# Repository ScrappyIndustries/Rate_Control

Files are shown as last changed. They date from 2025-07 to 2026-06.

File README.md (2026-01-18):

### [Nano RC12-3](Nano/RC12-3)
- uses a Nano (with ENC28J60 Ethernet shield) & an on-board mounted Cytron for rate control
	- 1 or 2 [MD13S](https://www.cytron.io/p-13amp-6v-30v-dc-motor-driver) for rate control
- self assembled through-hole board, least expensive
- controls two rates
- can be connected to a relay module with a 20 pin cable or dupont connectors
- work switch
- pressure switch
- [OSHPARK]([https://oshpark.com/shared_projects/UU8e90h9](https://oshpark.com/shared_projects/fRBlR1Se)
RC12-3

#
### [Teensy 4.1 RC11-2](Teensy/RC11-2_PCB)
- uses a Teensy & an on-board mounted Cytron for rate control
	- either (1) [MD13S](https://www.cytron.io/p-13amp-6v-30v-dc-motor-driver) for single rate control
 	- or (1) [MDD10A](https://www.cytron.io/p-10amp-5v-30v-dc-motor-driver-2-channels) for dual rate control
- small components are surface mount parts
- Teensy Ethernet 
- can control two rates and eight sections
	- 8 relays (SPDT 12V output)
	- (1) 5V or 12V analog (pressure) input, potentiometer adjustable filtering
	- (2) optically isolated digital (rate/pulse) inputs (5V or 12V)
- 3.3V I2C headers (Qwiic)
	- supports optional external RelayDriver5 I2C board
 - work switch
 - canbus
RC11-2

#
### [ESP32 RC15](ESP32/RC15)
- uses an ESP32 (optional W5500 Ethernet Module)
- mostly surface mount parts
- can control two rates and 7-14 sections
	- (2) DRV8870 motor drivers with reversible outputs for rates
	- (7) DRV8870 motor drivers for 7 reversible (motorized ball valve) outputs 
- (4) 5V analog inputs (or 2 differential inputs)
- (2) optically isolated digital (rate/pulse) inputs, up to 12V
- RS485 chip & header
- 3.3V I2C header
	- supports optional external RelayDriver5 I2C board
ESP32-RC15

#
### [RelayDriver5](RelayDriver5)
- PCA9535 based I2C IO expander
- designed to plug into 8 or 16 channel relay board with Qwiic cable
RelayDriver5 photo
#
### Firmware
https://github.com/SK21/AOG_RC

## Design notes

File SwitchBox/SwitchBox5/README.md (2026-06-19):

# Cab Switchbox 5

ESP32-based 16-input network switchbox for the AgOpenGPS Rate Controller.

## Repository contents

- `firmware/ESP32_Cab_Switchbox/` — Arduino firmware source.
- `release/` — precompiled ESP32 firmware files.
- `docs/` — user manual, printable HTML, screenshots, and manual generator.
- `hardware/SwitchBox5_Terminals_PCB_01/` — Rev 01 PCB production files.

## Hardware target

- ESP32 board: ESP32 DevKit / DOIT ESP32 DEVKIT V1
- Arduino FQBN: `esp32:esp32:esp32doit-devkit-v1`
- PCB: `SwitchBox5-Terminals-PCB-01`
- Recommended enclosure: Hammond `E1555K2GY`, NEMA 4X
- Board supply: 12-24 VDC
- Onboard buzzer: 12 V only; use a 12 V supply if buzzer operation is required

## Build

Install Arduino CLI and the Espressif ESP32 Arduino core, then run from the
repository root:

```powershell
arduino-cli compile `
  --fqbn esp32:esp32:esp32doit-devkit-v1 `
  --output-dir build `
  firmware/ESP32_Cab_Switchbox
```

## Flashing

The easiest full-device image is:

```text
release/ESP32_Cab_Switchbox.ino.merged.bin
```

Flash the merged image at address `0x0` with an ESP32 flashing tool.

Arduino CLI can also compile and upload the source directly:

```powershell
arduino-cli upload `
  -p COMx `
  --fqbn esp32:esp32:esp32doit-devkit-v1 `
  firmware/ESP32_Cab_Switchbox
```

Replace `COMx` with the switchbox serial port.

## Documentation

See `docs/CAB_SWITCHBOX_MANUAL.pdf` for setup, terminal assignments, network
configuration, wiring, buzzer behavior, and troubleshooting.

## Current build

Compiled June 19, 2026:

- Program storage: 1,045,571 bytes (79%)
- Dynamic memory: 50,504 bytes (15%)

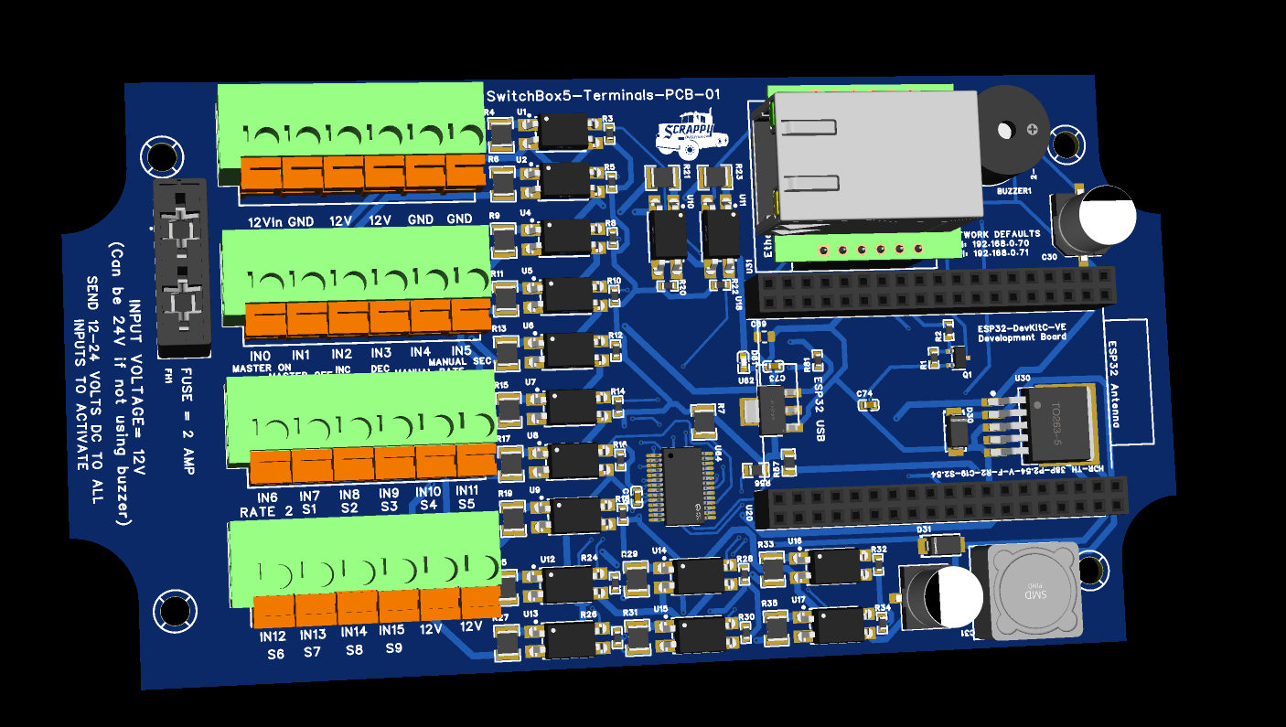
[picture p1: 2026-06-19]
SwitchBox/SwitchBox5/hardware/SwitchBox5_Terminals_PCB_01/Screenshot 2026-06-19 160806.png

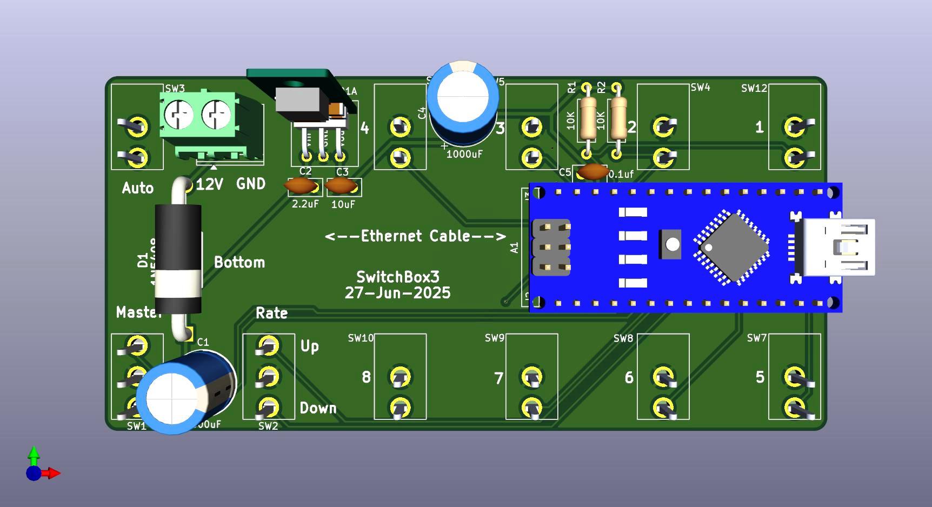
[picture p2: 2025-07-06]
SwitchBox/SwitchBox3/Switchbox3 Bottom.jpg

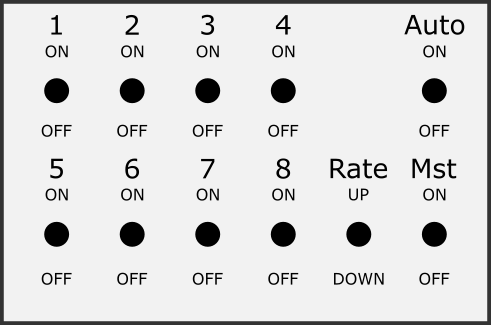
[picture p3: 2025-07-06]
SwitchBox/SwitchBox3/Switchbox3 decal.png

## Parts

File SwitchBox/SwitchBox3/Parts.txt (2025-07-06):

vinyl paper		https://www.amazon.ca/dp/B0BVMY4478?ref=ppx_yo2ov_dt_b_fed_asin_title

momentary switches	https://www.amazon.ca/Twidec-Miniature-Momentary-Waterproof-MTS-123-MZ/dp/B07VHCB1Q4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

toggle switches		https://www.amazon.ca/Twidec-Toggle-Position-Waterproof-MTS-101/dp/B07R9ZSYRZ?s=hi

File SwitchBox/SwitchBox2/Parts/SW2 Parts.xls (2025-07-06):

Description | Quantity | Part Number | Unit Price | Total | location
on/off switch | 5 | M2011SS1W03 | $6.21 | $31.05 | https://www.mouser.ca/ProductDetail/NKK-Switches/M2011SS1W03?qs=sGAEpiMZZMvudeGI7i40XOVezHpYSFdNIgSw9thGWMA%3D
on/off/on switch, mometary | 2 | M2018SS1W03 | $7.19 | $14.38 | https://www.mouser.ca/ProductDetail/NKK-Switches/M2018SS1W03
enclosure |  |  |  |  | https://www.amazon.ca/Waterproof-Electrical-Electronic-Enclosure-4-53x3-54/dp/B089K9ZSBC

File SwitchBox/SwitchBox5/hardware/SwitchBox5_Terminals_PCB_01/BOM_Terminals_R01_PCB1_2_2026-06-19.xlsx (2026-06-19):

No. | Quantity | Comment | Designator | Footprint | Value | Manufacturer Part | Manufacturer | Supplier Part | Supplier
1 | 1 | 2.4kHz | BUZZER1 | BUZ-TH_BD12.0-P7.60-D0.6-FD | 2.4kHz | TMB12A12 | 华能 | C96079 | LCSC
2 | 2 | 330uF | C30,C31 | CAP-SMD_BD8.0-L8.3-W8.3-LS9.9-FD | 330uF | EEEFT1V331GP | PANASONIC(松下) | C178599 | LCSC
3 | 1 | 22uF | C68 | Capacitor_SMD:C_0603_1608Metric | 22uF | CL10A226MQ8NRNC | SAMSUNG(三星) | C59461 | LCSC
4 | 1 | Device_C | C69 | Capacitor_SMD:C_0805_2012Metric | 10uF
5 | 1 | 22uF | C73 | C0603 | 22uF | CL10A226MQ8NRNC | SAMSUNG(三星) | C59461 | LCSC
6 | 1 | 10uF | C74 | C0603 | 10uF | CL10A106KP8NNNC | SAMSUNG(三星) | C19702 | LCSC
7 | 1 | 100nF | C75 | C0603 | 100nF | CC0603KRX7R9BB104 | YAGEO(国巨) | C14663 | LCSC
8 | 4 | DB142V-5.08-6P-GN | CN1,CN2,CN3,CN4 | CONN-TH_6P-P5.08_DIBO_DB142V-5.08-6P |  | DB142V-5.08-6P-GN | DORABO(地博电气) | C2898703 | LCSC
9 | 1 | 1N4148W-E3-18 | D1 | SOD-123_L2.7-W1.6-LS3.7-FD |  | 1N4148W-E3-18 | VISHAY(威世) | C191428 | LCSC
10 | 2 | SS24 | D30,D31 | SMA_L4.3-W2.6-LS5.2-RD |  | SS24 | MDD(辰达半导体) | C50645 | LCSC
11 | 1 | XL-1608UBC-06A | D81 | LED0603-R-RD |  | XL-1608UBC-06A | XINGLIGHT(成兴光) | C7371904 | LCSC
12 | 1 | XF-087 | FH1 | CONN-TH_XF-087 |  | XF-087 | XFCN(兴飞) | C41371864 | LCSC
13 | 2 | PM2.54-1*6 | H1,H2 | HDR-TH_6P-P2.54-V-F_4 |  | PM2.54-1*6 | ZHOURI(洲日) | C5224026 | LCSC
14 | 2 | AZ1117CH-3.3TRG1 | IC5,U62 | SOT-223-3_L6.5-W3.4-P2.30-LS7.0-BR |  | AZ1117CH-3.3TRG1 | DIODES(美台) | C92102 | LCSC
15 | 1 | 47uH | L30 | IND-SMD_L12.3-W12.3 | 47uH | SMDRI127-470MT | SXN(顺翔诺) | C9906 | LCSC
16 | 1 | AO3400A | Q1 | SOT-23-3_L3.0-W1.6-P1.90-LS2.8-BR |  | AO3400A | ElecSuper(静芯) | C5224194 | LCSC
17 | 1 | 100kΩ | R1 | R0603 | 100kΩ | FRC0603J104 TS | FOJAN(富捷) | C2907088 | LCSC
18 | 1 | 100Ω | R2 | R0603 | 100Ω | FRC0603J101 TS | FOJAN(富捷) | C2907089 | LCSC
19 | 16 | 4.7kΩ | R3,R5,R8,R10,R12,R14,R16,R18,R20,R22,R24,R26,R28,R30,R32,R34 | R0603 | 4.7kΩ | 0603WAF4701T5E | UNI-ROYAL(厚声) | C23162 | LCSC
20 | 17 | 4.7kΩ | R4,R6,R7,R9,R11,R13,R15,R17,R19,R21,R23,R25,R27,R29,R31,R33,R35 | R1210 | 4.7kΩ | 1210W2J0472T5E | UNI-ROYAL(厚声) | C26060 | LCSC
21 | 2 | 2.2kΩ | R56,R57 | R0805 | 2.2kΩ | ERJP06F2201V | PANASONIC(松下) | C441982 | LCSC
22 | 1 | 470Ω | R81 | R0603 | 470Ω | 0603WAF4700T5E | UNI-ROYAL(厚声) | C23179 | LCSC
23 | 16 | PC817C | U1,U2,U4,U5,U6,U7,U8,U9,U10,U11,U12,U13,U14,U15,U16,U17 | OPTO-SMD-4_L4.6-W6.5-P2.54-LS10.3-TL |  | PC817C | GOODWORK(固得沃克) | C3025164 | LCSC
24 | 2 | PM254-2-19-Z-8.5 | U18,U20 | HDR-TH_38P-P2.54-V-F-R2-C19-S2.54 |  | PM254-2-19-Z-8.5 | HCTL(华灿天禄) | C2897420 | LCSC
25 | 1 | LM2596S-5.0 | U30 | TO-263-5_L10.2-W8.9-P1.70-BR |  | LM2596S-5.0 | UMW(友台半导体) | C347421 | LCSC
26 | 1 | W5500_MODULE | U31 | COMM-TH_L25.0-W23.0_W5500_MODULE |  | W5500_MODULE |  | C9900227168 | LCSC
27 | 1 | MCP23017-E/SS | U64 | SSOP-28_L10.2-W5.3-P0.65-LS7.8-BL |  | MCP23017-E/SS | MICROCHIP(美国微芯) | C506653 | LCSC

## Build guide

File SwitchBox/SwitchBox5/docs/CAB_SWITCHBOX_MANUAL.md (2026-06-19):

# Cab Switchbox Manual

Last updated: June 19, 2026

Hardware shown in this manual: **SwitchBox5-Terminals-PCB-01 (Rev 01)**.

## Overview

The ESP32 Cab Switchbox is a network switch input module for the rate controller system. It reads up to 16 cab switch inputs, converts them into the switchbox packet used by the rate controller, and sends that packet over UDP by Ethernet and WiFi.

The switchbox is intended for cab controls such as:

- Master on / master off
- Rate up / rate down
- Manual rate override
- Manual section override
- Rate 2
- Work switch
- Section switches 1 through 16
- Board-mounted alarm buzzer output

The current firmware is in:

```text
ESP32_Cab_Switchbox/ESP32_Cab_Switchbox.ino
```

## Default Network Settings

The switchbox starts its own WiFi access point and can also use Ethernet.

Default settings:

| Item | Default |
| --- | --- |
| Access point name | `CabSwitchbox-XXXX` |
| Access point password | blank / open network |
| WiFi setup IP | `192.168.0.71` |
| Ethernet IP | `192.168.0.70` |
| Gateway | `192.168.0.1` |
| Subnet | `255.255.255.0` |
| Web page port | `80` |
| mDNS name | `cabswitchbox.local` |
| UDP send port | `29999` |
| Local UDP port | `28888` |

## Additional Parts Needed

The SwitchBox5 Rev 01 terminal PCB needs these additional parts installed before use:

| Part | Notes |
| --- | --- |
| 2 amp mini fuse | Installs in the fuse holder. Protects the input/switch-feed circuit. |
| ESP32-DEVKitC-VE | Main controller board. Install in the ESP32 header sockets. |
| W5500 Ethernet Module | Ethernet network module. Install in the W5500 module header. |
| Hammond `E1555K2GY` enclosure | Polycarbonate NEMA 4X enclosure, 6.3 x 3.5 x 3.5 inches. The SwitchBox5 PCB fits this enclosure. |

## Enclosure

The SwitchBox5 PCB fits the **Hammond Manufacturing E1555K2GY**
polycarbonate enclosure:

| Item | Specification |
| --- | --- |
| Manufacturer | Hammond Manufacturing |
| Part number | `E1555K2GY` |
| Outside size | 6.3 x 3.5 x 3.5 inches |
| Protection rating | NEMA 4X |
| Material | Polycarbonate |

Plan cable glands, Ethernet access, switch wiring, and board mounting before
drilling the enclosure. Keep the lid sealing surface clear of wiring and
hardware so the NEMA 4X seal is maintained.

## Power And Switch Feed Terminals

Power the board from the input power terminals:

The upper six-position terminal block on Rev 01 is ordered left to right:

| Position | Terminal | Use |
| --- | --- | --- |
| 1 | `12Vin` | Connect to supply +12-24 VDC. |
| 2 | `GND` | Connect to supply negative / ground. |
| 3 | `12V` | Fused +12-24 VDC output for switch feeds. |
| 4 | `12V` | Fused +12-24 VDC output for switch feeds. |
| 5 | `GND` | Ground return terminal. |
| 6 | `GND` | Ground return terminal. |

The `12V` terminals are fused outputs from the board input power. Use these fused `12V` terminals to feed the operator switches, then return the switched voltage to the desired `INx` input.

Typical wiring:

```text
Supply +12-24 VDC -------- 12Vin
Supply negative ---------- GND

Fused 12V terminal ------- switch ------- INx
```

The Rev 01 input power fuse is 2 amps. The fused `12V` terminals are intended for feeding switch inputs, not for powering heavy loads.

The PCB electronics and switch inputs can operate from **12-24 VDC**. However,
the buzzer is a **12 V board-mounted component connected directly to input
power**. The buzzer will only operate correctly when the board is powered from
12 VDC. Do not expect buzzer operation with a 24 V supply, and do not apply
24 V to the installed 12 V buzzer.

## Rev 01 Terminal Layout

The four six-position terminal blocks are ordered as follows:

| Block | Left-to-right terminal order |
| --- | --- |
| Power | `12Vin`, `GND`, `12V`, `12V`, `GND`, `GND` |
| Inputs 0-5 | `IN0`, `IN1`, `IN2`, `IN3`, `IN4`, `IN5` |
| Inputs 6-11 | `IN6`, `IN7`, `IN8`, `IN9`, `IN10`, `IN11` |
| Inputs 12-15 / switch feed | `IN12`, `IN13`, `IN14`, `IN15`, `12V`, `12V` |

The Rev 01 silkscreen also identifies the default functions below the input
terminals: master on/off, rate increase/decrease, manual rate, manual section,
Rate 2, and sections S1 through S9.

## Accessing The Setup Page

### Using The Switchbox WiFi Access Point

1. Power the Cab Switchbox.
2. On a phone, tablet, or laptop, connect to the WiFi network named `CabSwitchbox`.
3. Open a browser and go to:

```text
http://192.168.0.71/
```

If mDNS is working on the device you are using, this may also work:

```text
http://cabswitchbox.local/
```

### Using Ethernet

1. Connect the switchbox Ethernet port to the same network as the rate controller / setup computer.
2. Make sure the computer is on the same subnet as the switchbox.
3. Open:

```text
http://192.168.0.70/
```

If needed, first connect by WiFi and change the Ethernet IP address to match the network you are using.

## Setup Page Sections

The setup page has a live status area and a configuration form. After changing settings, click **Save and restart**. The switchbox saves the settings to EEPROM and restarts.

### Status

The status area shows:

| Status item | Meaning |
| --- | --- |
| Input board | The switch input board is detected and ready. |
| Ethernet | Ethernet hardware is detected and the link is up. |
| WiFi station | The switchbox is connected to an existing WiFi network. |
| Buzzer | The GPIO27 buzzer output is currently on. |
| Alarm packet | A recent alarm packet has been received from Rate Controller. |
| Alarm active | Rate Controller is requesting the cab buzzer. |
| Packet | The six-byte packet being sent to the rate controller. |
| Decoded PGN32618 | Human-readable state of the outgoing switchbox packet. |
| Inputs | Live state and assigned action for each input `IN0` through `IN15`. |

### Network Settings

| Setting | Description |
| --- | --- |
| Ethernet IP | Static IP used by the Ethernet interface. |
| WiFi IP | IP used by the switchbox access point. |
| Gateway | Gateway used for Ethernet and station WiFi. |
| Subnet | Subnet mask. |
| Also connect to existing WiFi network | Enables WiFi station mode in addition to the switchbox access point. |
| Existing WiFi SSID | Name of the WiFi network the switchbox should join. |
| Existing WiFi Password | Password for the existing WiFi network. |
| Access Point Name | Name of the WiFi network created by the switchbox. |
| Access Point Password | Password for the switchbox access point. Leave blank for open WiFi, or use 8 or more characters. |

### Input Settings

| Setting | Default | Description |
| --- | --- | --- |
| Override section switches ON | Off | Forces mapped section switch inputs ON without jumpers. Use this when section switches are not installed. |
| Send period ms | `100` | How often the switchbox packet is sent. Valid range is 50 to 1000 ms. |
| Pulse length ms | `250` | Length of master and rate pulses. Valid range is 50 to 1000 ms. |
| IN0-IN15 action | See table below | Assigns what each physical input does. |

### Alarm Buzzer Settings

| Setting | Default | Description |
| --- | --- | --- |
| Buzzer level | `Reduced` | Select `Off`, `Reduced`, or `Full` for the board buzzer. |
| Test buzzer | n/a | Sounds the buzzer for two seconds without changing saved settings. |

## Default Input Map

Factory/default input assignments:

| Input | Default action | Typical wiring |
| --- | --- | --- |
| IN0 | Master on | Momentary switch feeding +12-24 VDC to IN0 |
| IN1 | Master off | Momentary switch feeding +12-24 VDC to IN1 |
| IN2 | Rate up | Momentary switch feeding +12-24 VDC to IN2 |
| IN3 | Rate down | Momentary switch feeding +12-24 VDC to IN3 |
| IN4 | Manual rate override | Toggle switch feeding +12-24 VDC to IN4 |
| IN5 | Manual section override | Toggle switch feeding +12-24 VDC to IN5 |
| IN6 | Rate 2 | Toggle switch feeding +12-24 VDC to IN6 |
| IN7 | Section 1 | Toggle switch feeding +12-24 VDC to IN7 |
| IN8 | Section 2 | Toggle switch feeding +12-24 VDC to IN8 |
| IN9 | Section 3 | Toggle switch feeding +12-24 VDC to IN9 |
| IN10 | Section 4 | Toggle switch feeding +12-24 VDC to IN10 |
| IN11 | Section 5 | Toggle switch feeding +12-24 VDC to IN11 |
| IN12 | Section 6 | Toggle switch feeding +12-24 VDC to IN12 |
| IN13 | Section 7 | Toggle switch feeding +12-24 VDC to IN13 |
| IN14 | Section 8 | Toggle switch feeding +12-24 VDC to IN14 |
| IN15 | Section 9 | Toggle switch feeding +12-24 VDC to IN15 |

Any input can be reassigned from the web page.

Available actions:

| Action | Behavior |
| --- | --- |
| Disabled | Input is ignored. |
| Master on | Momentary master on pulse. |
| Master off | Momentary master off pulse. |
| Rate up | Rate up command. |
| Rate down | Rate down command. |
| Work switch | Implement up/down permissive. ON allows application; OFF forces master/sections off when Work Switch is enabled in the Rate Controller app. |
| Manual section override | When active, requests manual section override. |
| Manual rate override | When active, requests manual rate override. |
| Rate 2 | Sends Rate 2 while active. |
| Master | Maintained master switch. ON sends master on; OFF sends master off. |
| Section 1-16 | Sends the matching section switch bit while active. |

## Wiring Inputs

The switchbox5 board inputs are made for 12-24 VDC switch signals. Each switch input turns ON when +12-24 VDC is applied to that `INx` terminal.

Input behavior:

- An open / unpowered input reads OFF.
- Applying +12-24 VDC to an `INx` terminal reads ON.
- The 12-24 VDC supply negative must be connected to the switchbox input `GND`.

Typical switchbox5 field wiring:

```text
12Vin ---------------- supply +12-24 VDC
GND ------------------- supply negative
12V fused output ------ switch ------ INx
```

For a momentary button, use a normally-open button between a fused `12V` terminal and the assigned `INx` terminal.

For a toggle switch, use a maintained switch between a fused `12V` terminal and the assigned `INx` terminal.

Use the `IN0` through `IN15` input terminals on the switchbox board. Do not connect field wiring to internal board components.

## Wiring The Master And Rate Controls

A simple installation without section switches can use only:

| Function | Default input |
| --- | --- |
| Master on | IN0 |
| Master off | IN1 |
| Rate up | IN2 |
| Rate down | IN3 |
| Manual rate override | IN4 |
| Manual section override | IN5 |
| Rate 2 | IN6 |

Wire each installed switch so it feeds fused +12-24 VDC from a `12V` terminal to the assigned `INx` terminal when the switch is ON or pressed.

If section switches are not installed, enable **Override section switches ON**. This makes all inputs assigned to `Section 1` through `Section 16` behave as ON in the outgoing packet, so the system does not require jumper wires on the unused section switch inputs.

## Wiring Section Switches

For normal section switch operation:

1. Leave **Override section switches ON** unchecked.
2. Wire each section toggle so it feeds fused +12-24 VDC from a `12V` terminal to its assigned `INx` terminal when ON.

Default section switch wiring:

| Section | Default input |
| --- | --- |
| Section 1 | IN7 |
| Section 2 | IN8 |
| Section 3 | IN9 |
| Section 4 | IN10 |
| Section 5 | IN11 |
| Section 6 | IN12 |
| Section 7 | IN13 |
| Section 8 | IN14 |
| Section 9 | IN15 |

Sections 10 through 16 can be used by reassigning inputs from the setup page. The board has 16 total inputs, so using more section switches may require disabling or moving other functions.

## Override Section Switches ON

Use **Override section switches ON** when the operator does not have physical section switches installed.

When enabled:

- Inputs assigned to `Section 1` through `Section 16` are forced ON in the switchbox packet.
- Master, rate, and override inputs still use the real physical switch state.
- No section input jumpers are required.

When disabled:

- Section inputs behave normally.
- An open / unpowered section input is OFF.

## Work Switch

The `Work switch` input is normally used for an implement lift switch, height switch, whisker switch, pressure switch, or other signal that tells the rate controller whether the implement is in work.

Typical use:

```text
Implement down / in work = +12-24 VDC to Work switch input = ON
Implement up / out of work = input unpowered = OFF
```

When Work Switch is enabled in the Rate Controller app, it acts as a master permissive:

- Work switch ON allows the rate controller to apply when the master and section conditions are also satisfied.
- Work switch OFF forces master/sections off.
- It does not replace Auto Rate or Auto Section. Those are separate switchbox functions.

In the Rate Controller app, Work Switch must be enabled in the switch settings. If it is not enabled there, the app ignores the work switch signal and behaves as if work is always allowed.

## Alarm Buzzer Output

The active 12 V alarm buzzer is installed directly on the SwitchBox5 PCB. It is
not an additional external part. The buzzer is driven from ESP32 Dev Board pin
`GPIO27` through the onboard low-side MOSFET.

The buzzer receives board input voltage directly. Therefore:

- With a 12 VDC board supply, the onboard buzzer operates normally.
- The remainder of the switchbox can operate from 12-24 VDC.
- With a 24 VDC board supply, the installed 12 V buzzer must not be operated.

GPIO27 does not need an external pull-up. The 100k pulldown keeps the buzzer off while the ESP32 is booting or reset.

## Packet Behavior

The switchbox sends a six-byte packet to UDP port `29999`.

Packet layout:

| Byte | Meaning |
| --- | --- |
| 0 | Header byte `106` |
| 1 | Header byte `127` |
| 2 | Status bits |
| 3 | Section bits 1-8 |
| 4 | Section bits 9-16 |
| 5 | Checksum |

Status byte bits:

| Bit | Meaning |
| --- | --- |
| 0 | Rate 2 |
| 1 | Master on |
| 2 | Master off |
| 3 | Rate up |
| 4 | Rate down |
| 5 | Auto section |
| 6 | Auto rate |
| 7 | Work switch |

Section byte behavior:

- Byte 3 bit 0 = Section 1
- Byte 3 bit 7 = Section 8
- Byte 4 bit 0 = Section 9
- Byte 4 bit 7 = Section 16

The checksum is the sum of bytes 0 through 4, stored in one byte.

## Recommended First Setup

1. Power the switchbox.
2. Connect to WiFi network `CabSwitchbox`.
3. Open `http://192.168.0.71/`.
4. Confirm the status page shows `Input board` ON.
5. If using Ethernet, set the Ethernet IP to match the rate controller network.
6. If section switches are not installed, check **Override section switches ON**.
7. Confirm each installed switch changes state in the Inputs status area.
8. Click **Save and restart**.
9. After restart, verify the rate controller responds to master and rate commands.

## Example Setups

### Master And Rate Only, No Section Switches

Use this when only master and rate controls are installed.

Recommended settings:

| Setting | Value |
| --- | --- |
| Override section switches ON | Checked |
| IN0 | Master on |
| IN1 | Master off |
| IN2 | Rate up |
| IN3 | Rate down |
| IN4-IN6 | As needed |
| IN7-IN15 | Section 1-9, or Disabled |

### Full Section Switchbox

Use this when physical section switches are installed.

Recommended settings:

| Setting | Value |
| --- | --- |
| Override section switches ON | Unchecked |
| IN0-IN6 | Master/rate controls |
| IN7-IN15 | Section 1-9 by default |

### Maintained Master Switch

If using a maintained master switch instead of separate master on/off buttons:

1. Set one input action to `Master`.
2. Wire the maintained switch so it feeds fused +12-24 VDC from a `12V` terminal to that input when ON.
3. Set unused `Master on` and `Master off` inputs to `Disabled`, or reassign them.

When the maintained master input turns ON, the switchbox sends master on. When it turns OFF, the switchbox sends master off.

## Troubleshooting

### Cannot Open The Web Page

- Make sure the switchbox is powered.
- If using WiFi, connect to the `CabSwitchbox` access point first.
- Try `http://192.168.0.71/` for WiFi access.
- Try `http://192.168.0.70/` for Ethernet access.
- If the IP address was changed, connect by the other interface or reflash/reset configuration if needed.

### Input Board Shows OFF

The switchbox is not detecting the input board.

Check:

- Input board power and ground
- I2C SDA/SCL wiring
- Soldering around the input board

If Input board is OFF, switch input states will not be reliable.

### Ethernet Shows OFF

Check:

- Ethernet cable
- Link lights on the W5500 module or connector
- Network switch/router
- W5500 SPI wiring and chip select

The switchbox can still be configured by WiFi if Ethernet is unavailable.

### Inputs Do Not Turn ON

For the switchbox5 board, each input needs +12-24 VDC on the `INx` terminal to turn ON.

Check:

- The switch feed has +12-24 VDC.
- The switch output is connected to the correct `INx` terminal.
- The 12-24 VDC supply negative is connected to switchbox input `GND`.
- The input is assigned to the expected action in the setup page.

### Missing Section Switches Stop Operation

Enable **Override section switches ON**. This forces section switch bits ON without changing master or rate input behavior.

### Rate Up Or Rate Down Sticks ON

Check whether the input is assigned to `Rate up` or `Rate down` and whether the physical switch is stuck active. The status page shows live input states.

Check whether the physical switch is stuck on, or whether +12-24 VDC is being backfed into that input.

### WiFi Station Does Not Connect

Check:

- SSID spelling
- Password spelling
- WiFi signal strength
- Whether the WiFi network uses a compatible 2.4 GHz mode

The switchbox access point remains available even when station WiFi is enabled.

## Notes For Firmware Updates

Configuration is stored in EEPROM. The current firmware uses config version 3.

Defaults are restored when:

- EEPROM does not contain a valid switchbox config.
- The stored config version is not recognized.

The firmware includes migration for older switchbox config versions 1 and 2.

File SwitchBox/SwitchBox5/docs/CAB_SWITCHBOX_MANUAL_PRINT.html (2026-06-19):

# Cab Switchbox Manual

Last updated: June 19, 2026

Hardware shown in this manual: SwitchBox5-Terminals-PCB-01 (Rev 01).

## Overview

The ESP32 Cab Switchbox is a network switch input module for the rate controller system. It reads up to 16 cab switch inputs, converts them into the switchbox packet used by the rate controller, and sends that packet over UDP by Ethernet and WiFi.

The switchbox is intended for cab controls such as:

- Master on / master off
- Rate up / rate down
- Manual rate override
- Manual section override
- Rate 2
- Work switch
- Section switches 1 through 16
- Board-mounted alarm buzzer output

The current firmware is in:

ESP32_Cab_Switchbox/ESP32_Cab_Switchbox.ino

## Default Network Settings

The switchbox starts its own WiFi access point and can also use Ethernet.

Default settings:

Item | Default
Access point name | CabSwitchbox-XXXX
Access point password | blank / open network
WiFi setup IP | 192.168.0.71
Ethernet IP | 192.168.0.70
Gateway | 192.168.0.1
Subnet | 255.255.255.0
Web page port | 80
mDNS name | cabswitchbox.local
UDP send port | 29999
Local UDP port | 28888

## Additional Parts Needed

The SwitchBox5 Rev 01 terminal PCB needs these additional parts installed before use:

Part | Notes
2 amp mini fuse | Installs in the fuse holder. Protects the input/switch-feed circuit.
ESP32-DEVKitC-VE | Main controller board. Install in the ESP32 header sockets.
W5500 Ethernet Module | Ethernet network module. Install in the W5500 module header.
Hammond E1555K2GY enclosure | Polycarbonate NEMA 4X enclosure, 6.3 x 3.5 x 3.5 inches. The SwitchBox5 PCB fits this enclosure.

## Enclosure

The SwitchBox5 PCB fits the Hammond Manufacturing E1555K2GY

polycarbonate enclosure:

Item | Specification
Manufacturer | Hammond Manufacturing
Part number | E1555K2GY
Outside size | 6.3 x 3.5 x 3.5 inches
Protection rating | NEMA 4X
Material | Polycarbonate

Plan cable glands, Ethernet access, switch wiring, and board mounting before

drilling the enclosure. Keep the lid sealing surface clear of wiring and

hardware so the NEMA 4X seal is maintained.

## Board Power And Switch Feed

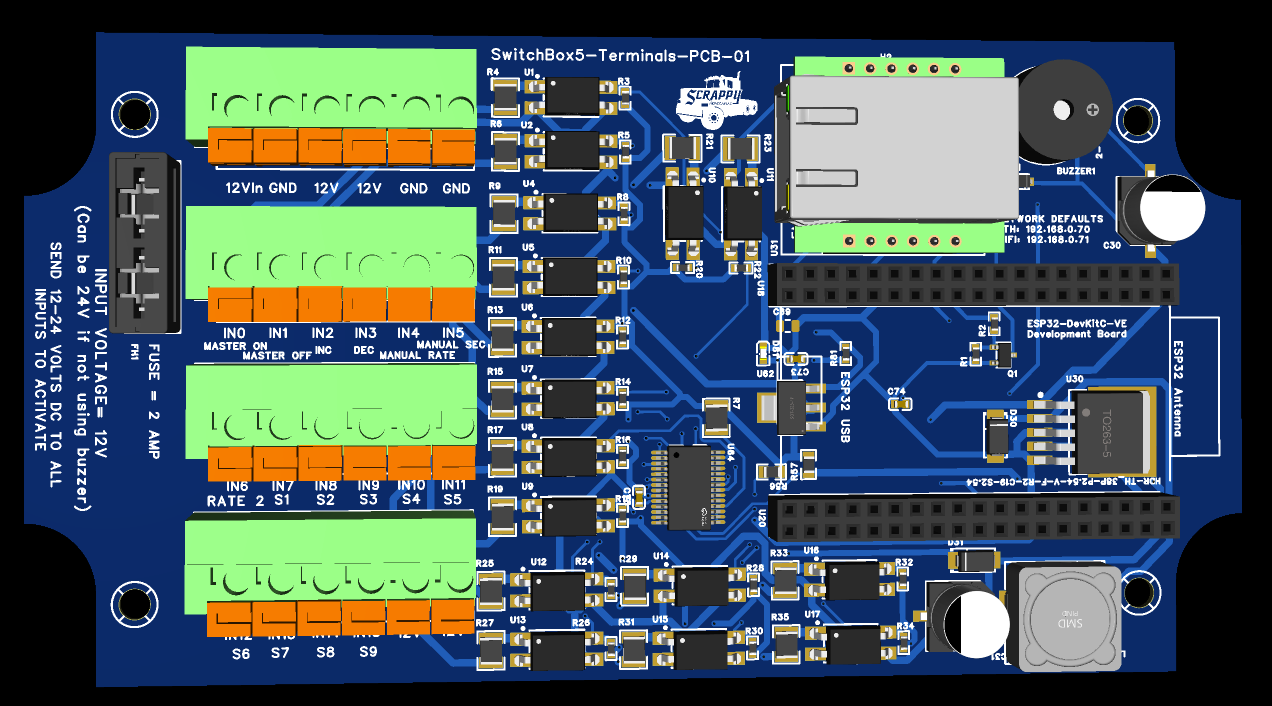
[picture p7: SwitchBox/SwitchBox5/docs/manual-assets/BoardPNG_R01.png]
SwitchBox5 Rev 01 board terminal layout


SwitchBox5-Terminals-PCB-01 (Rev 01). Connect board power to 12Vin and GND. Use the fused 12V terminals through switches to power the IN0-IN15 inputs.

## Power And Switch Feed Terminals

Power the board from the input power terminals:

The upper six-position terminal block on Rev 01 is ordered left to right:

Position | Terminal | Use
1 | 12Vin | Connect to supply +12-24 VDC.
2 | GND | Connect to supply negative / ground.
3 | 12V | Fused +12-24 VDC output for switch feeds.
4 | 12V | Fused +12-24 VDC output for switch feeds.
5 | GND | Ground return terminal.
6 | GND | Ground return terminal.

The 12V terminals are fused outputs from the board input power. Use these fused 12V terminals to feed the operator switches, then return the switched voltage to the desired INx input.

Typical wiring:

Supply +12-24 VDC -------- 12Vin

Supply negative ---------- GND

Fused 12V terminal ------- switch ------- INx

The Rev 01 input power fuse is 2 amps. The fused 12V terminals are intended for feeding switch inputs, not for powering heavy loads.

The PCB electronics and switch inputs can operate from 12-24 VDC. However,

the buzzer is a **12 V board-mounted component connected directly to input

power**. The buzzer will only operate correctly when the board is powered from

12 VDC. Do not expect buzzer operation with a 24 V supply, and do not apply

24 V to the installed 12 V buzzer.

## Rev 01 Terminal Layout

The four six-position terminal blocks are ordered as follows:

Block | Left-to-right terminal order
Power | 12Vin, GND, 12V, 12V, GND, GND
Inputs 0-5 | IN0, IN1, IN2, IN3, IN4, IN5
Inputs 6-11 | IN6, IN7, IN8, IN9, IN10, IN11
Inputs 12-15 / switch feed | IN12, IN13, IN14, IN15, 12V, 12V

The Rev 01 silkscreen also identifies the default functions below the input

terminals: master on/off, rate increase/decrease, manual rate, manual section,

Rate 2, and sections S1 through S9.

## Accessing The Setup Page

### Using The Switchbox WiFi Access Point

1. Power the Cab Switchbox.
2. On a phone, tablet, or laptop, connect to the WiFi network named CabSwitchbox.
3. Open a browser and go to:

http://192.168.0.71/

If mDNS is working on the device you are using, this may also work:

http://cabswitchbox.local/

### Using Ethernet

1. Connect the switchbox Ethernet port to the same network as the rate controller / setup computer.
2. Make sure the computer is on the same subnet as the switchbox.
3. Open:

http://192.168.0.70/

If needed, first connect by WiFi and change the Ethernet IP address to match the network you are using.

## Setup Page Screenshots

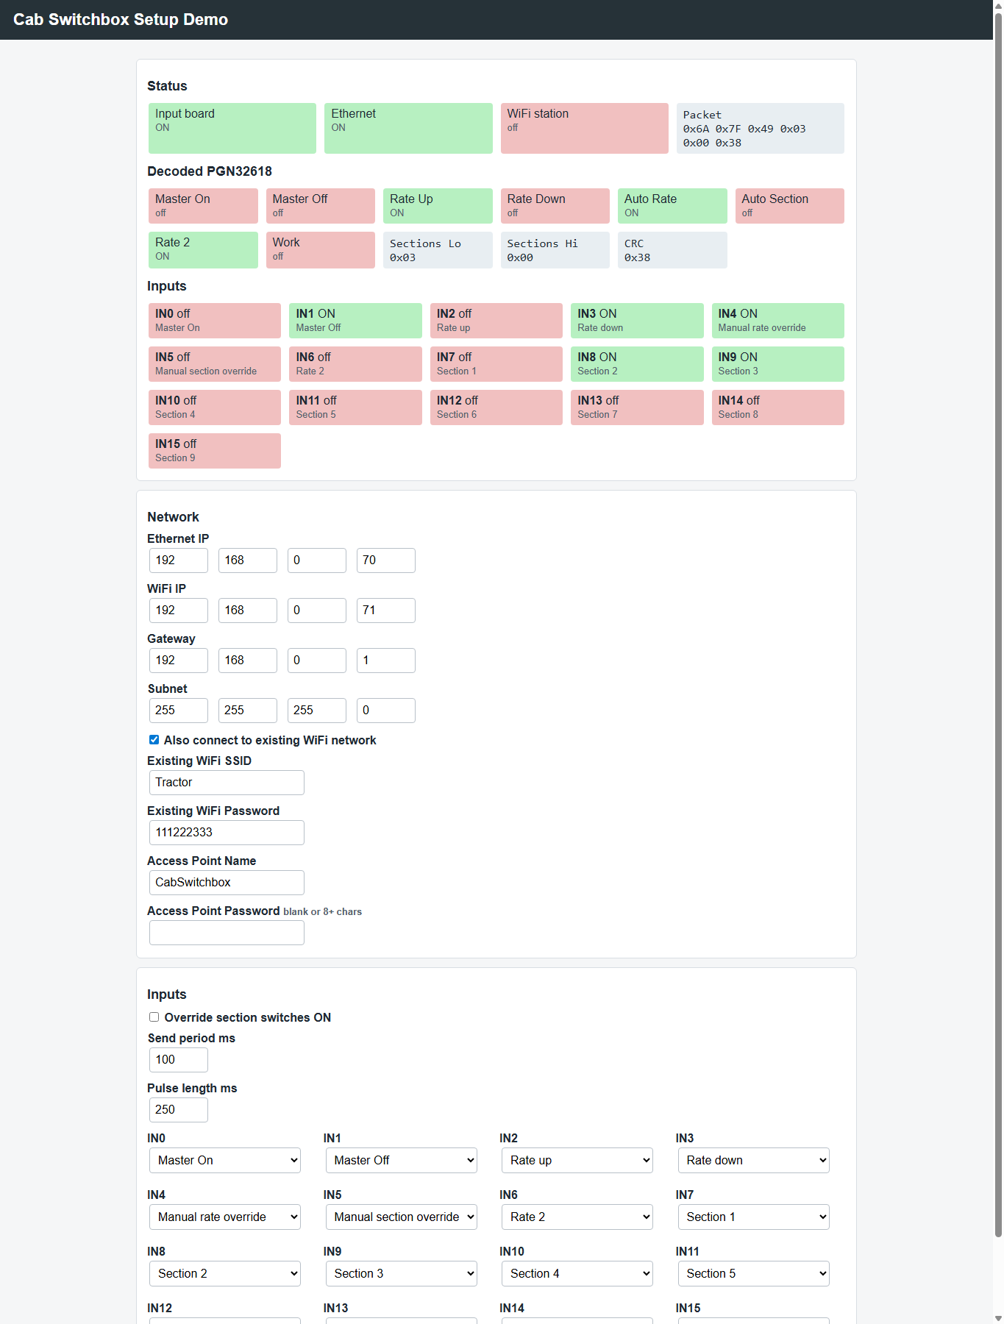
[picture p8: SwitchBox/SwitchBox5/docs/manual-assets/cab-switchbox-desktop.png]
Cab Switchbox setup page desktop screenshot


Desktop setup page with live status, decoded packet, network settings, and input configuration.

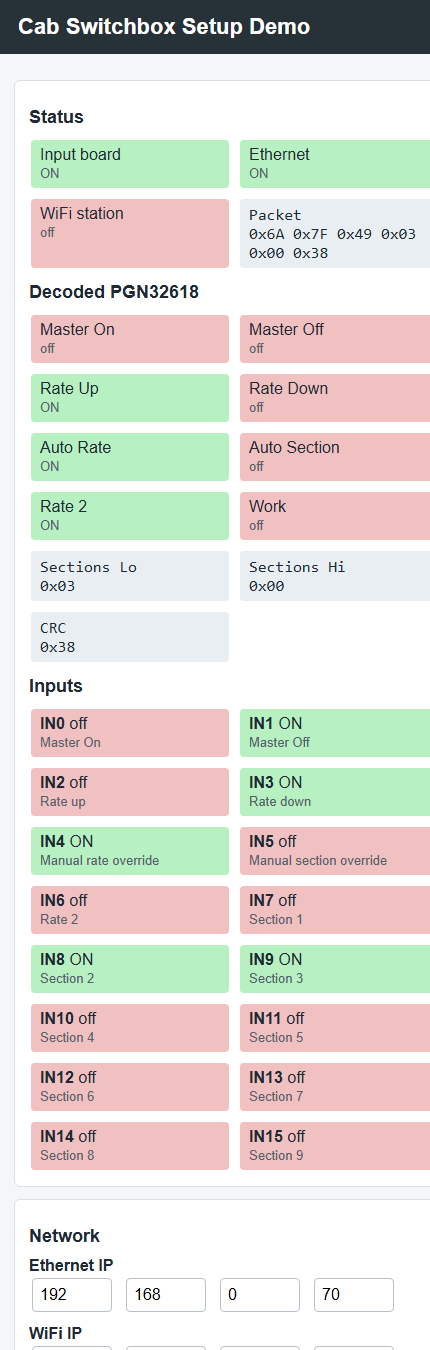
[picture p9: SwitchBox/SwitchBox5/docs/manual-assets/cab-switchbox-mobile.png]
Cab Switchbox setup page mobile screenshot


Mobile layout used when configuring the switchbox from a phone or tablet in the cab.

## Setup Page Sections

The setup page has a live status area and a configuration form. After changing settings, click Save and restart. The switchbox saves the settings to EEPROM and restarts.

### Status

The status area shows:

Status item | Meaning
Input board | The switch input board is detected and ready.
Ethernet | Ethernet hardware is detected and the link is up.
WiFi station | The switchbox is connected to an existing WiFi network.
Buzzer | The GPIO27 buzzer output is currently on.
Alarm packet | A recent alarm packet has been received from Rate Controller.
Alarm active | Rate Controller is requesting the cab buzzer.
Packet | The six-byte packet being sent to the rate controller.
Decoded PGN32618 | Human-readable state of the outgoing switchbox packet.
Inputs | Live state and assigned action for each input IN0 through IN15.

### Network Settings

Setting | Description
Ethernet IP | Static IP used by the Ethernet interface.
WiFi IP | IP used by the switchbox access point.
Gateway | Gateway used for Ethernet and station WiFi.
Subnet | Subnet mask.
Also connect to existing WiFi network | Enables WiFi station mode in addition to the switchbox access point.
Existing WiFi SSID | Name of the WiFi network the switchbox should join.
Existing WiFi Password | Password for the existing WiFi network.
Access Point Name | Name of the WiFi network created by the switchbox.
Access Point Password | Password for the switchbox access point. Leave blank for open WiFi, or use 8 or more characters.

### Input Settings

Setting | Default | Description
Override section switches ON | Off | Forces mapped section switch inputs ON without jumpers. Use this when section switches are not installed.
Send period ms | 100 | How often the switchbox packet is sent. Valid range is 50 to 1000 ms.
Pulse length ms | 250 | Length of master and rate pulses. Valid range is 50 to 1000 ms.
IN0-IN15 action | See table below | Assigns what each physical input does.

### Alarm Buzzer Settings

Setting | Default | Description
Buzzer level | Reduced | Select Off, Reduced, or Full for the board buzzer.
Test buzzer | n/a | Sounds the buzzer for two seconds without changing saved settings.

## Default Input Map

Factory/default input assignments:

Input | Default action | Typical wiring
IN0 | Master on | Momentary switch feeding +12-24 VDC to IN0
IN1 | Master off | Momentary switch feeding +12-24 VDC to IN1
IN2 | Rate up | Momentary switch feeding +12-24 VDC to IN2
IN3 | Rate down | Momentary switch feeding +12-24 VDC to IN3
IN4 | Manual rate override | Toggle switch feeding +12-24 VDC to IN4
IN5 | Manual section override | Toggle switch feeding +12-24 VDC to IN5
IN6 | Rate 2 | Toggle switch feeding +12-24 VDC to IN6
IN7 | Section 1 | Toggle switch feeding +12-24 VDC to IN7
IN8 | Section 2 | Toggle switch feeding +12-24 VDC to IN8
IN9 | Section 3 | Toggle switch feeding +12-24 VDC to IN9
IN10 | Section 4 | Toggle switch feeding +12-24 VDC to IN10
IN11 | Section 5 | Toggle switch feeding +12-24 VDC to IN11
IN12 | Section 6 | Toggle switch feeding +12-24 VDC to IN12
IN13 | Section 7 | Toggle switch feeding +12-24 VDC to IN13
IN14 | Section 8 | Toggle switch feeding +12-24 VDC to IN14
IN15 | Section 9 | Toggle switch feeding +12-24 VDC to IN15

Any input can be reassigned from the web page.

Available actions:

Action | Behavior
Disabled | Input is ignored.
Master on | Momentary master on pulse.
Master off | Momentary master off pulse.
Rate up | Rate up command.
Rate down | Rate down command.
Work switch | Implement up/down permissive. ON allows application; OFF forces master/sections off when Work Switch is enabled in the Rate Controller app.
Manual section override | When active, requests manual section override.
Manual rate override | When active, requests manual rate override.
Rate 2 | Sends Rate 2 while active.
Master | Maintained master switch. ON sends master on; OFF sends master off.
Section 1-16 | Sends the matching section switch bit while active.

## Wiring Inputs

The switchbox5 board inputs are made for 12-24 VDC switch signals. Each switch input turns ON when +12-24 VDC is applied to that INx terminal.

Input behavior:

- An open / unpowered input reads OFF.
- Applying +12-24 VDC to an INx terminal reads ON.
- The 12-24 VDC supply negative must be connected to the switchbox input GND.

Typical switchbox5 field wiring:

12Vin ---------------- supply +12-24 VDC

GND ------------------- supply negative

12V fused output ------ switch ------ INx

For a momentary button, use a normally-open button between a fused 12V terminal and the assigned INx terminal.

For a toggle switch, use a maintained switch between a fused 12V terminal and the assigned INx terminal.

Use the IN0 through IN15 input terminals on the switchbox board. Do not connect field wiring to internal board components.

## Wiring The Master And Rate Controls

A simple installation without section switches can use only:

Function | Default input
Master on | IN0
Master off | IN1
Rate up | IN2
Rate down | IN3
Manual rate override | IN4
Manual section override | IN5
Rate 2 | IN6

Wire each installed switch so it feeds fused +12-24 VDC from a 12V terminal to the assigned INx terminal when the switch is ON or pressed.

If section switches are not installed, enable Override section switches ON. This makes all inputs assigned to Section 1 through Section 16 behave as ON in the outgoing packet, so the system does not require jumper wires on the unused section switch inputs.

## Wiring Section Switches

For normal section switch operation:

1. Leave Override section switches ON unchecked.
2. Wire each section toggle so it feeds fused +12-24 VDC from a 12V terminal to its assigned INx terminal when ON.

Default section switch wiring:

Section | Default input
Section 1 | IN7
Section 2 | IN8
Section 3 | IN9
Section 4 | IN10
Section 5 | IN11
Section 6 | IN12
Section 7 | IN13
Section 8 | IN14
Section 9 | IN15

Sections 10 through 16 can be used by reassigning inputs from the setup page. The board has 16 total inputs, so using more section switches may require disabling or moving other functions.

## Override Section Switches ON

Use Override section switches ON when the operator does not have physical section switches installed.

When enabled:

- Inputs assigned to Section 1 through Section 16 are forced ON in the switchbox packet.
- Master, rate, and override inputs still use the real physical switch state.
- No section input jumpers are required.

When disabled:

- Section inputs behave normally.
- An open / unpowered section input is OFF.

## Work Switch

The Work switch input is normally used for an implement lift switch, height switch, whisker switch, pressure switch, or other signal that tells the rate controller whether the implement is in work.

Typical use:

Implement down / in work = +12-24 VDC to Work switch input = ON

Implement up / out of work = input unpowered = OFF

When Work Switch is enabled in the Rate Controller app, it acts as a master permissive:

- Work switch ON allows the rate controller to apply when the master and section conditions are also satisfied.
- Work switch OFF forces master/sections off.
- It does not replace Auto Rate or Auto Section. Those are separate switchbox functions.

In the Rate Controller app, Work Switch must be enabled in the switch settings. If it is not enabled there, the app ignores the work switch signal and behaves as if work is always allowed.

## Alarm Buzzer Output

The active 12 V alarm buzzer is installed directly on the SwitchBox5 PCB. It is

not an additional external part. The buzzer is driven from ESP32 Dev Board pin

GPIO27 through the onboard low-side MOSFET.

The buzzer receives board input voltage directly. Therefore:

- With a 12 VDC board supply, the onboard buzzer operates normally.
- The remainder of the switchbox can operate from 12-24 VDC.
- With a 24 VDC board supply, the installed 12 V buzzer must not be operated.

GPIO27 does not need an external pull-up. The 100k pulldown keeps the buzzer off while the ESP32 is booting or reset.

## Packet Behavior

The switchbox sends a six-byte packet to UDP port 29999.

Packet layout:

Byte | Meaning
0 | Header byte 106
1 | Header byte 127
2 | Status bits
3 | Section bits 1-8
4 | Section bits 9-16
5 | Checksum

Status byte bits:

Bit | Meaning
0 | Rate 2
1 | Master on
2 | Master off
3 | Rate up
4 | Rate down
5 | Auto section
6 | Auto rate
7 | Work switch

Section byte behavior:

- Byte 3 bit 0 = Section 1
- Byte 3 bit 7 = Section 8
- Byte 4 bit 0 = Section 9
- Byte 4 bit 7 = Section 16

The checksum is the sum of bytes 0 through 4, stored in one byte.

## Recommended First Setup

1. Power the switchbox.
2. Connect to WiFi network CabSwitchbox.
3. Open http://192.168.0.71/.
4. Confirm the status page shows Input board ON.
5. If using Ethernet, set the Ethernet IP to match the rate controller network.
6. If section switches are not installed, check Override section switches ON.
7. Confirm each installed switch changes state in the Inputs status area.
8. Click Save and restart.
9. After restart, verify the rate controller responds to master and rate commands.

## Example Setups

### Master And Rate Only, No Section Switches

Use this when only master and rate controls are installed.

Recommended settings:

Setting | Value
Override section switches ON | Checked
IN0 | Master on
IN1 | Master off
IN2 | Rate up
IN3 | Rate down
IN4-IN6 | As needed
IN7-IN15 | Section 1-9, or Disabled

### Full Section Switchbox

Use this when physical section switches are installed.

Recommended settings:

Setting | Value
Override section switches ON | Unchecked
IN0-IN6 | Master/rate controls
IN7-IN15 | Section 1-9 by default

### Maintained Master Switch

If using a maintained master switch instead of separate master on/off buttons:

1. Set one input action to Master.
2. Wire the maintained switch so it feeds fused +12-24 VDC from a 12V terminal to that input when ON.
3. Set unused Master on and Master off inputs to Disabled, or reassign them.

When the maintained master input turns ON, the switchbox sends master on. When it turns OFF, the switchbox sends master off.

## Troubleshooting

### Cannot Open The Web Page

- Make sure the switchbox is powered.
- If using WiFi, connect to the CabSwitchbox access point first.
- Try http://192.168.0.71/ for WiFi access.
- Try http://192.168.0.70/ for Ethernet access.
- If the IP address was changed, connect by the other interface or reflash/reset configuration if needed.

### Input Board Shows OFF

The switchbox is not detecting the input board.

Check:

- Input board power and ground
- I2C SDA/SCL wiring
- Soldering around the input board

If Input board is OFF, switch input states will not be reliable.

### Ethernet Shows OFF

Check:

- Ethernet cable
- Link lights on the W5500 module or connector
- Network switch/router
- W5500 SPI wiring and chip select

The switchbox can still be configured by WiFi if Ethernet is unavailable.

### Inputs Do Not Turn ON

For the switchbox5 board, each input needs +12-24 VDC on the INx terminal to turn ON.

Check:

- The switch feed has +12-24 VDC.
- The switch output is connected to the correct INx terminal.
- The 12-24 VDC supply negative is connected to switchbox input GND.
- The input is assigned to the expected action in the setup page.

### Missing Section Switches Stop Operation

Enable Override section switches ON. This forces section switch bits ON without changing master or rate input behavior.

### Rate Up Or Rate Down Sticks ON

Check whether the input is assigned to Rate up or Rate down and whether the physical switch is stuck active. The status page shows live input states.

Check whether the physical switch is stuck on, or whether +12-24 VDC is being backfed into that input.

### WiFi Station Does Not Connect

Check:

- SSID spelling
- Password spelling
- WiFi signal strength
- Whether the WiFi network uses a compatible 2.4 GHz mode

The switchbox access point remains available even when station WiFi is enabled.

## Notes For Firmware Updates

Configuration is stored in EEPROM. The current firmware uses config version 3.

Defaults are restored when:

- EEPROM does not contain a valid switchbox config.
- The stored config version is not recognized.

The firmware includes migration for older switchbox config versions 1 and 2.

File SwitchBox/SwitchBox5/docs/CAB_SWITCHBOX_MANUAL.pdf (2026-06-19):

# Cab Switchbox Manual

ESP32 network switch input setup, wiring, and troubleshooting

Last updated: June 19, 2026

Hardware shown in this manual: SwitchBox5-Terminals-PCB-01 (Rev 01).

## Overview

The ESP32 Cab Switchbox is a network switch input module for the rate controller system. It reads up to 16 cab switch inputs, converts them into the switchbox packet used by the rate controller, and sends that packet over UDP by Ethernet and WiFi.

The switchbox is intended for cab controls such as:

Master on / master off
Rate up / rate down
Manual rate override
Manual section override
Rate 2
Work switch
Section switches 1 through 16 Board-mounted alarm buzzer output

The current firmware is in:

ESP32_Cab_Switchbox/ESP32_Cab_Switchbox.ino

## Default Network Settings

The switchbox starts its own WiFi access point and can also use Ethernet.

Default settings:

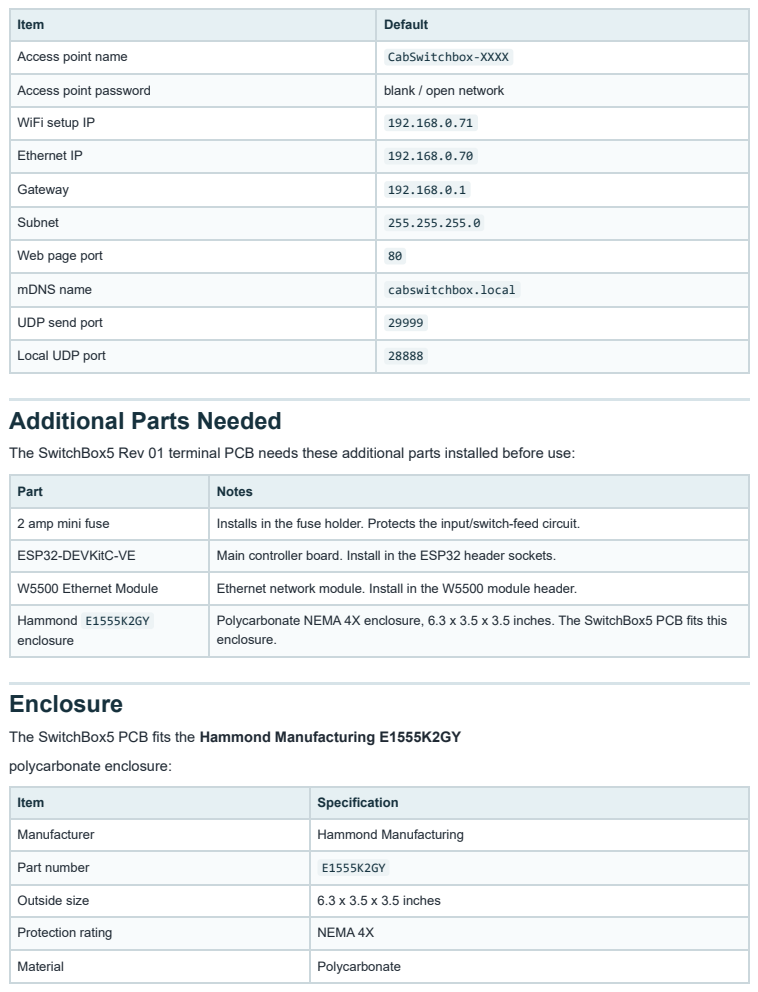
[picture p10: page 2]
Enclosure

Item | Default

Access point name | CabSwitchbox-XXXX

Access point password | blank / open network

WiFi setup IP | 192.168.0.71

Ethernet IP | 192.168.0.70

Gateway | 192.168.0.1

Subnet | 255.255.255.0

Web page port | 80

mDNS name | cabswitchbox.local

UDP send port | 29999

Local UDP port | 28888

Additional Parts Needed

The SwitchBox5 Rev 01 terminal PCB needs these additional parts installed before use:

Part | Notes

2 amp mini fuse | Installs in the fuse holder. Protects the input/switch-feed circuit.

ESP32-DEVKitC-VE | Main controller board. Install in the ESP32 header sockets.

W5500 Ethernet Module | Ethernet network module. Install in the W5500 module header.

Hammond E1555K2GY enclosure | Polycarbonate NEMA 4X enclosure, 6.3 x 3.5 x 3.5 inches. The SwitchBox5 PCB fits this enclosure.

The SwitchBox5 PCB fits the Hammond Manufacturing E1555K2GY
polycarbonate enclosure:

Item | Specification

Manufacturer | Hammond Manufacturing

Part number | E1555K2GY

Outside size | 6.3 x 3.5 x 3.5 inches

Protection rating | NEMA 4X

Material | Polycarbonate

## Board Power And Switch Feed

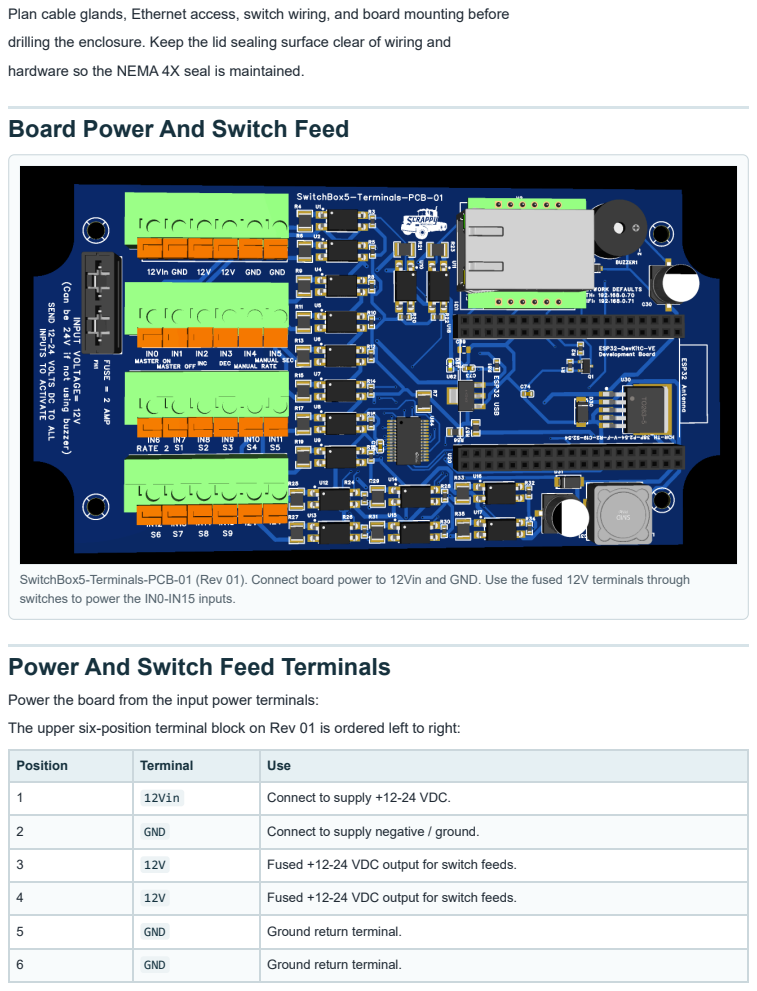
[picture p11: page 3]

Plan cable glands, Ethernet access, switch wiring, and board mounting before
drilling the enclosure. Keep the lid sealing surface clear of wiring and
hardware so the NEMA 4X seal is maintained.

SwitchBox5-Terminals-PCB-01 (Rev 01). Connect board power to 12Vin and GND. Use the fused 12V terminals through
switches to power the IN0-IN15 inputs.

Power And Switch Feed Terminals

Power the board from the input power terminals:
The upper six-position terminal block on Rev 01 is ordered left to right:

Position | Terminal | Use

1 | 12Vin | Connect to supply +12-24 VDC.

2 | GND | Connect to supply negative / ground.

3 | 12V | Fused +12-24 VDC output for switch feeds.

4 | 12V | Fused +12-24 VDC output for switch feeds.

5 | GND | Ground return terminal.

6 | GND | Ground return terminal.

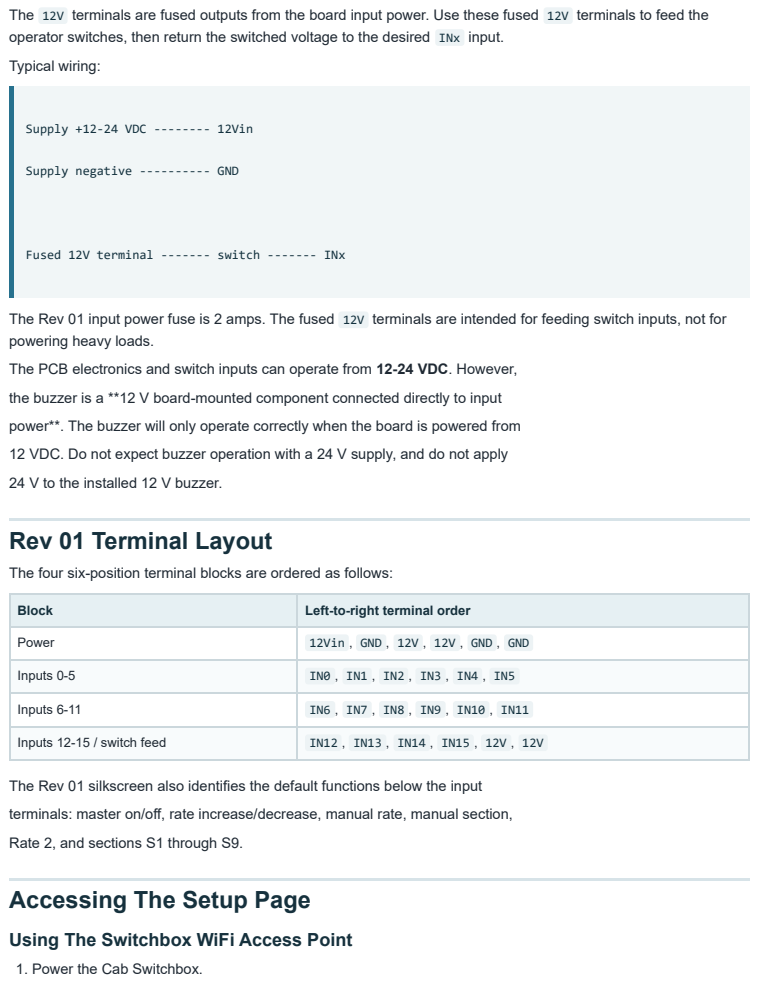
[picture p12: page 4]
Supply +12-24 VDC -------- 12Vin

The 12V terminals are fused outputs from the board input power. Use these fused 12V terminals to feed the
operator switches, then return the switched voltage to the desired INx input.
Typical wiring:

Supply negative ---------- GND

Fused 12V terminal ------- switch ------- INx

The Rev 01 input power fuse is 2 amps. The fused 12V terminals are intended for feeding switch inputs, not for
powering heavy loads.
The PCB electronics and switch inputs can operate from 12-24 VDC. However,
the buzzer is a **12 V board-mounted component connected directly to input
power**. The buzzer will only operate correctly when the board is powered from
12 VDC. Do not expect buzzer operation with a 24 V supply, and do not apply
24 V to the installed 12 V buzzer.

Rev 01 Terminal Layout

The four six-position terminal blocks are ordered as follows:

Block | Left-to-right terminal order

Power | 12Vin , GND , 12V , 12V , GND , GND

Inputs 0-5 | IN0 , IN1 , IN2 , IN3 , IN4 , IN5

Inputs 6-11 | IN6 , IN7 , IN8 , IN9 , IN10 , IN11

Inputs 12-15 / switch feed | IN12 , IN13 , IN14 , IN15 , 12V , 12V

The Rev 01 silkscreen also identifies the default functions below the input
terminals: master on/off, rate increase/decrease, manual rate, manual section,
Rate 2, and sections S1 through S9.

Accessing The Setup Page

Using The Switchbox WiFi Access Point

1. Power the Cab Switchbox.

2. On a phone, tablet, or laptop, connect to the WiFi network named CabSwitchbox .
3. Open a browser and go to:

http://192.168.0.71/

If mDNS is working on the device you are using, this may also work:

http://cabswitchbox.local/

### Using Ethernet

1. Connect the switchbox Ethernet port to the same network as the rate controller / setup computer.
2. Make sure the computer is on the same subnet as the switchbox.
3. Open:

http://192.168.0.70/

If needed, first connect by WiFi and change the Ethernet IP address to match the network you are using.

## Setup Page Screenshots

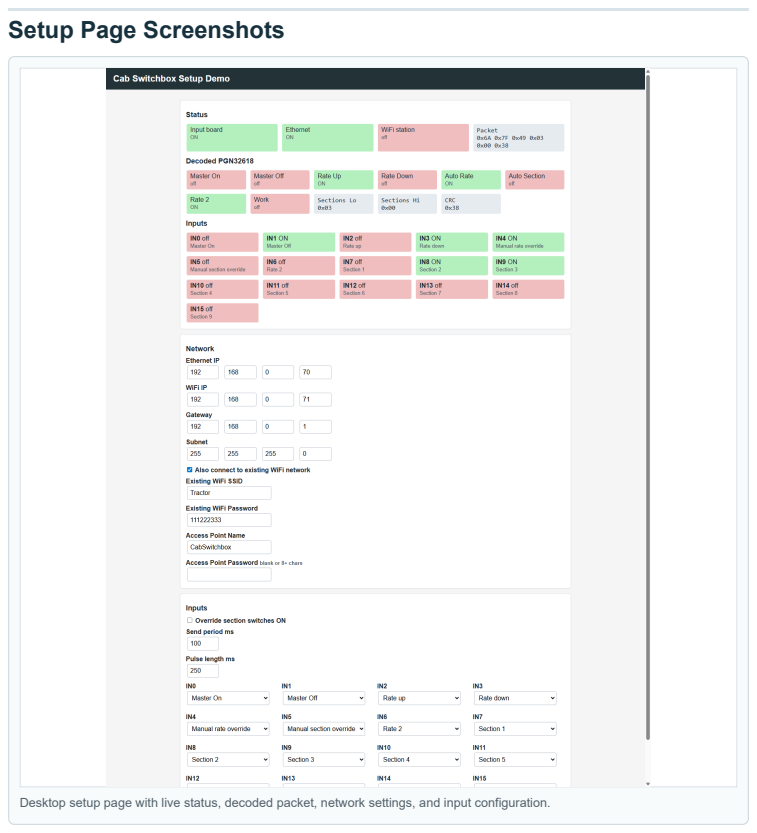
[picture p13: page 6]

Desktop setup page with live status, decoded packet, network settings, and input configuration.

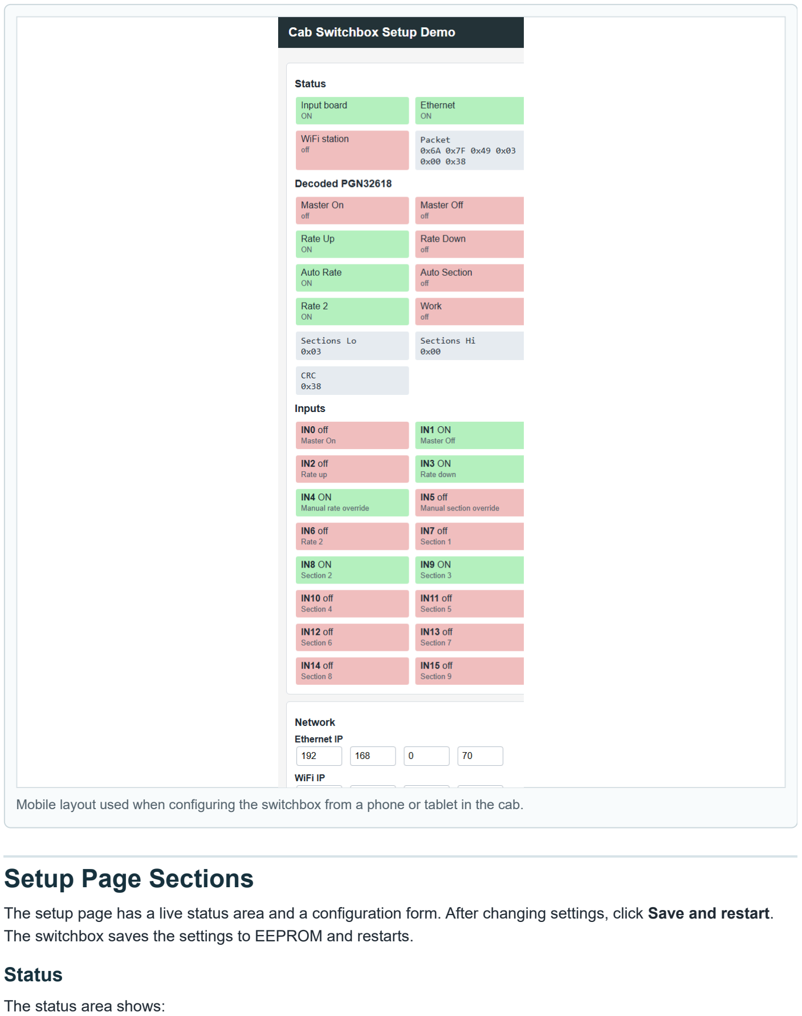
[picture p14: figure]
Setup Page Sections; Status; The status area shows:

Mobile layout used when configuring the switchbox from a phone or tablet in the cab.

The setup page has a live status area and a configuration form. After changing settings, click Save and restart. The switchbox saves the settings to EEPROM and restarts.

Status item | Meaning
Input board | The switch input board is detected and ready.
Ethernet | Ethernet hardware is detected and the link is up.
WiFi station | The switchbox is connected to an existing WiFi network.
Buzzer | The GPIO27 buzzer output is currently on.
Alarm packet | A recent alarm packet has been received from Rate Controller.
Alarm active | Rate Controller is requesting the cab buzzer.
Packet | The six-byte packet being sent to the rate controller.
Decoded PGN32618 | Human-readable state of the outgoing switchbox packet.
Inputs | Live state and assigned action for each input IN0 through IN15 .

### Network Settings

Setting | Description
Ethernet IP | Static IP used by the Ethernet interface.
WiFi IP | IP used by the switchbox access point.
Gateway | Gateway used for Ethernet and station WiFi.
Subnet | Subnet mask.
Also connect to existing WiFi network | Enables WiFi station mode in addition to the switchbox access point.
Existing WiFi SSID | Name of the WiFi network the switchbox should join.
Existing WiFi Password | Password for the existing WiFi network.
Access Point Name | Name of the WiFi network created by the switchbox.
Access Point Password | Password for the switchbox access point. Leave blank for open WiFi, or use 8 or more characters.

### Input Settings

Setting | Default | Description
Override section switches ON | Off | Forces mapped section switch inputs ON without jumpers. Use this when section switches are not installed.
Send period ms | 100 | How often the switchbox packet is sent. Valid range is 50 to 1000 ms.
Pulse length ms | 250 | Length of master and rate pulses. Valid range is 50 to 1000 ms.
IN0-IN15 action | See table below | Assigns what each physical input does.

### Alarm Buzzer Settings

## Default Input Map

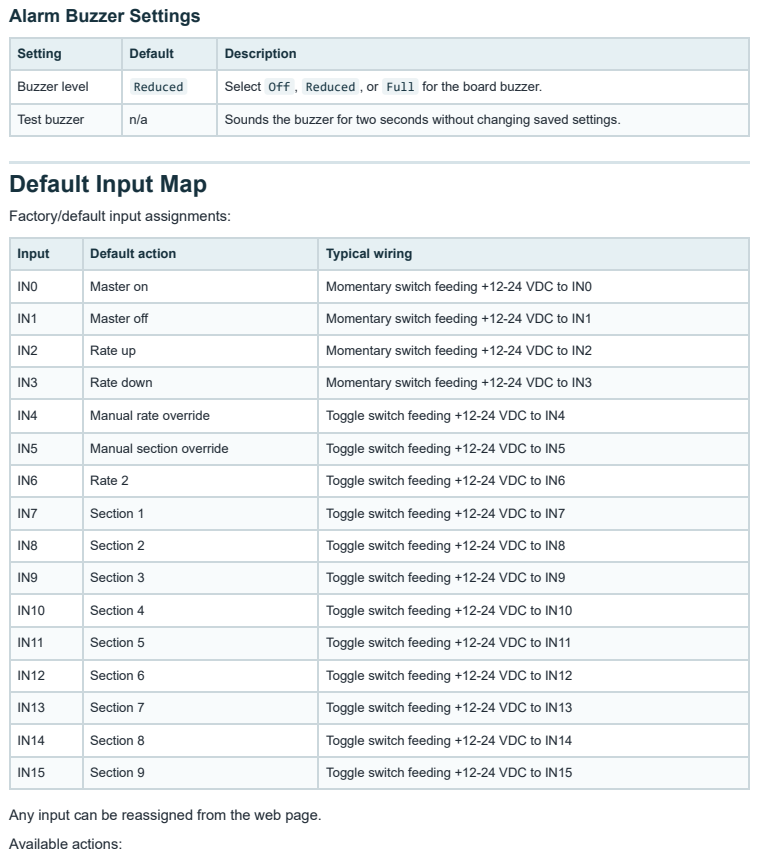
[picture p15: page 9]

Setting | Default | Description

Buzzer level | Reduced | Select Off , Reduced , or Full for the board buzzer.

Test buzzer | n/a | Sounds the buzzer for two seconds without changing saved settings.

Factory/default input assignments:

Input | Default action | Typical wiring

IN0 | Master on | Momentary switch feeding +12-24 VDC to IN0

IN1 | Master off | Momentary switch feeding +12-24 VDC to IN1

IN2 | Rate up | Momentary switch feeding +12-24 VDC to IN2

IN3 | Rate down | Momentary switch feeding +12-24 VDC to IN3

IN4 | Manual rate override | Toggle switch feeding +12-24 VDC to IN4

IN5 | Manual section override | Toggle switch feeding +12-24 VDC to IN5

IN6 | Rate 2 | Toggle switch feeding +12-24 VDC to IN6

IN7 | Section 1 | Toggle switch feeding +12-24 VDC to IN7

IN8 | Section 2 | Toggle switch feeding +12-24 VDC to IN8

IN9 | Section 3 | Toggle switch feeding +12-24 VDC to IN9

IN10 | Section 4 | Toggle switch feeding +12-24 VDC to IN10

IN11 | Section 5 | Toggle switch feeding +12-24 VDC to IN11

IN12 | Section 6 | Toggle switch feeding +12-24 VDC to IN12

IN13 | Section 7 | Toggle switch feeding +12-24 VDC to IN13

IN14 | Section 8 | Toggle switch feeding +12-24 VDC to IN14

IN15 | Section 9 | Toggle switch feeding +12-24 VDC to IN15

Any input can be reassigned from the web page.
Available actions:

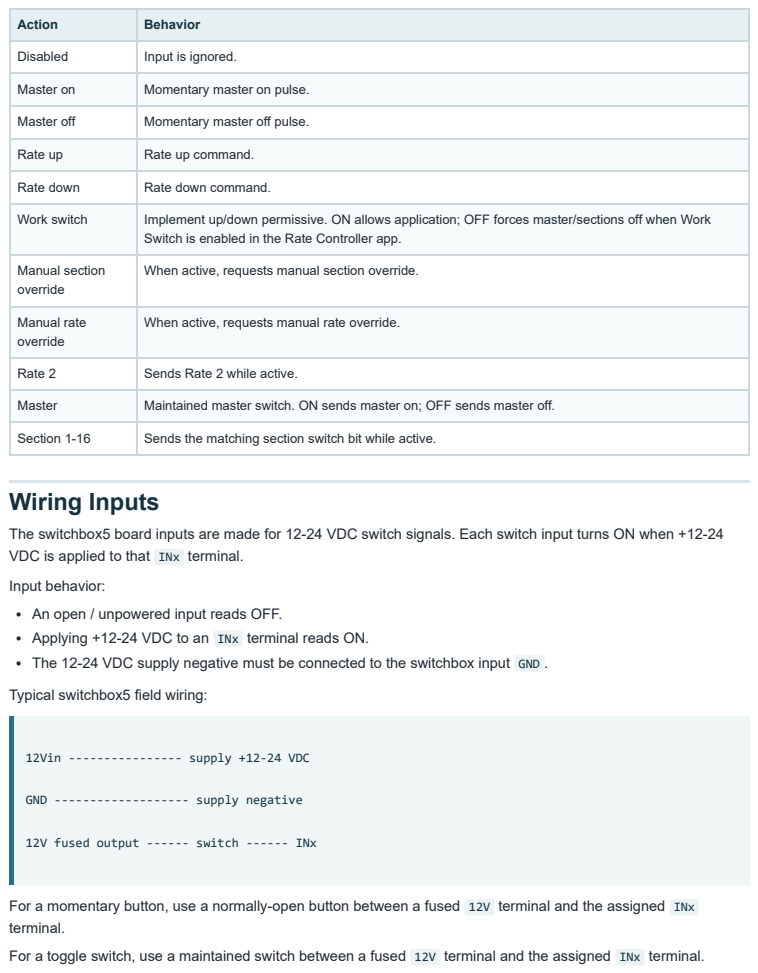
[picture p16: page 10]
Wiring Inputs; 12Vin ---------------- supply +12-24 VDC

Action | Behavior

Disabled | Input is ignored.

Master on | Momentary master on pulse.

Master off | Momentary master off pulse.

Rate up | Rate up command.

Rate down | Rate down command.

Work switch | Implement up/down permissive. ON allows application; OFF forces master/sections off when Work Switch is enabled in the Rate Controller app.

Manual section override | When active, requests manual section override.

Manual rate override | When active, requests manual rate override.

Rate 2 | Sends Rate 2 while active.

Master | Maintained master switch. ON sends master on; OFF sends master off.

Section 1-16 | Sends the matching section switch bit while active.

The switchbox5 board inputs are made for 12-24 VDC switch signals. Each switch input turns ON when +12-24
VDC is applied to that INx terminal.
Input behavior:
An open / unpowered input reads OFF.
Applying +12-24 VDC to an INx terminal reads ON.
The 12-24 VDC supply negative must be connected to the switchbox input GND .

Typical switchbox5 field wiring:

GND ------------------- supply negative

12V fused output ------ switch ------ INx

For a momentary button, use a normally-open button between a fused 12V terminal and the assigned INx
terminal.
For a toggle switch, use a maintained switch between a fused 12V terminal and the assigned INx terminal.

## Wiring The Master And Rate Controls

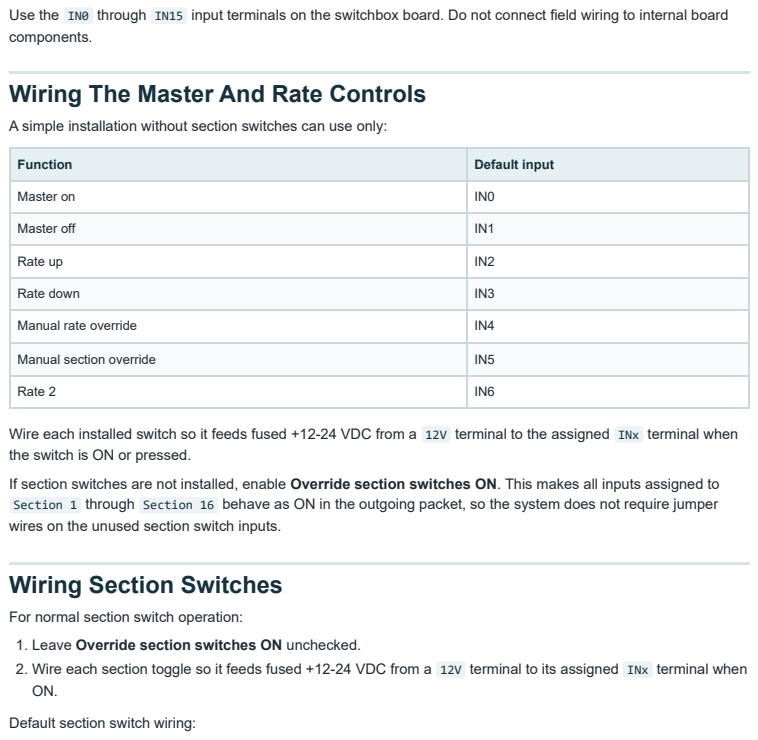
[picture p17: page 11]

Use the IN0 through IN15 input terminals on the switchbox board. Do not connect field wiring to internal board
components.

A simple installation without section switches can use only:

Function | Default input

Master on | IN0

Master off | IN1

Rate up | IN2

Rate down | IN3

Manual rate override | IN4

Manual section override | IN5

Rate 2 | IN6

Wire each installed switch so it feeds fused +12-24 VDC from a 12V terminal to the assigned INx terminal when
the switch is ON or pressed.
If section switches are not installed, enable Override section switches ON. This makes all inputs assigned to
Section 1 through Section 16 behave as ON in the outgoing packet, so the system does not require jumper
wires on the unused section switch inputs.

Wiring Section Switches

For normal section switch operation:
1. Leave Override section switches ON unchecked.
2. Wire each section toggle so it feeds fused +12-24 VDC from a 12V terminal to its assigned INx terminal when

Default section switch wiring:

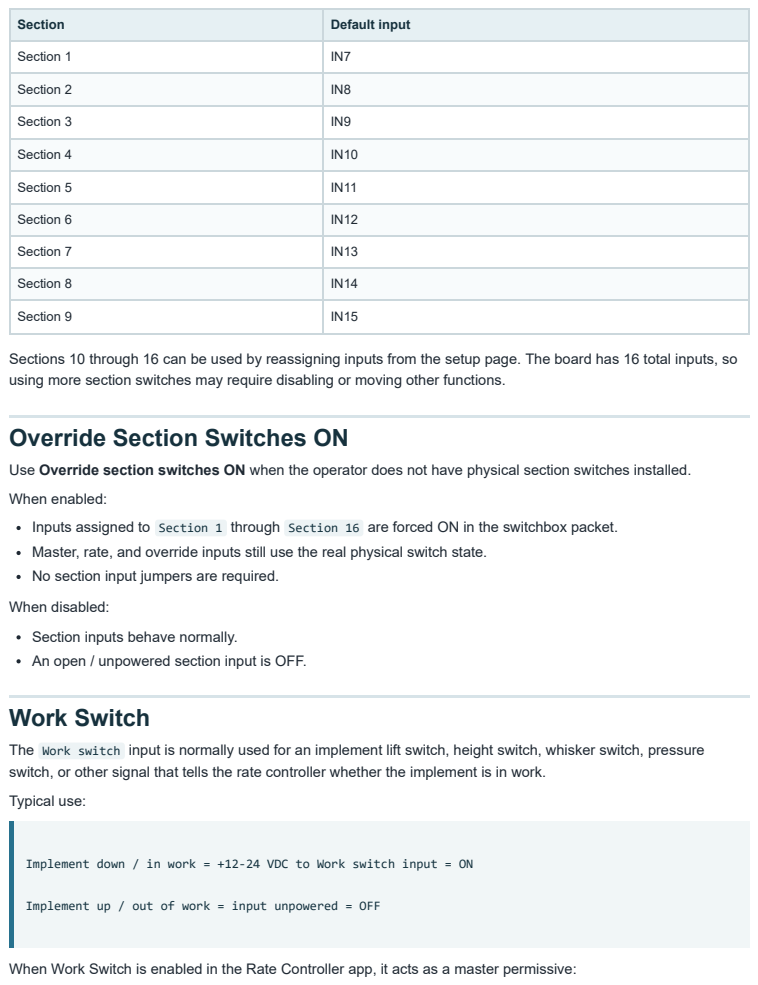
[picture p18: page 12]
Work Switch

Section | Default input

Section 1 | IN7

Section 2 | IN8

Section 3 | IN9

Section 4 | IN10

Section 5 | IN11

Section 6 | IN12

Section 7 | IN13

Section 8 | IN14

Section 9 | IN15

Sections 10 through 16 can be used by reassigning inputs from the setup page. The board has 16 total inputs, so
using more section switches may require disabling or moving other functions.

Override Section Switches ON

Use Override section switches ON when the operator does not have physical section switches installed.
When enabled:
Inputs assigned to Section 1 through Section 16 are forced ON in the switchbox packet.
Master, rate, and override inputs still use the real physical switch state.
No section input jumpers are required.

When disabled:
Section inputs behave normally.
An open / unpowered section input is OFF.

The Work switch input is normally used for an implement lift switch, height switch, whisker switch, pressure
switch, or other signal that tells the rate controller whether the implement is in work.
Typical use:

Implement down / in work = +12-24 VDC to Work switch input = ON

Implement up / out of work = input unpowered = OFF

When Work Switch is enabled in the Rate Controller app, it acts as a master permissive:

## Alarm Buzzer Output

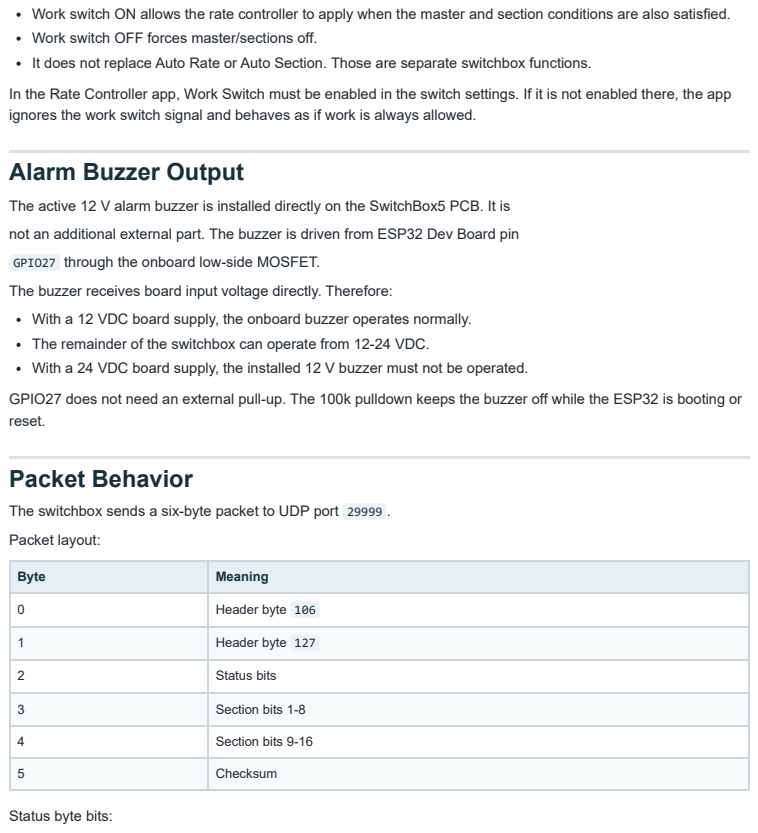
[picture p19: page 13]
Packet Behavior

Work switch ON allows the rate controller to apply when the master and section conditions are also satisfied.
Work switch OFF forces master/sections off.
It does not replace Auto Rate or Auto Section. Those are separate switchbox functions.

In the Rate Controller app, Work Switch must be enabled in the switch settings. If it is not enabled there, the app
ignores the work switch signal and behaves as if work is always allowed.

The active 12 V alarm buzzer is installed directly on the SwitchBox5 PCB. It is
not an additional external part. The buzzer is driven from ESP32 Dev Board pin
GPIO27 through the onboard low-side MOSFET.
The buzzer receives board input voltage directly. Therefore:
With a 12 VDC board supply, the onboard buzzer operates normally.
The remainder of the switchbox can operate from 12-24 VDC.
With a 24 VDC board supply, the installed 12 V buzzer must not be operated.

GPIO27 does not need an external pull-up. The 100k pulldown keeps the buzzer off while the ESP32 is booting or
reset.

The switchbox sends a six-byte packet to UDP port 29999 .
Packet layout:

Byte | Meaning

0 | Header byte 106

1 | Header byte 127

2 | Status bits

3 | Section bits 1-8

4 | Section bits 9-16

5 | Checksum

Status byte bits:

Bit | Meaning
0 | Rate 2
1 | Master on
2 | Master off
3 | Rate up
4 | Rate down
5 | Auto section
6 | Auto rate
7 | Work switch

Section byte behavior:

Byte 3 bit 0 = Section 1
Byte 3 bit 7 = Section 8
Byte 4 bit 0 = Section 9
Byte 4 bit 7 = Section 16

The checksum is the sum of bytes 0 through 4, stored in one byte.

## Recommended First Setup

1. Power the switchbox.
2. Connect to WiFi network CabSwitchbox .
3. Open http://192.168.0.71/ .
4. Confirm the status page shows Input board ON.
5. If using Ethernet, set the Ethernet IP to match the rate controller network.
6. If section switches are not installed, check Override section switches ON.
7. Confirm each installed switch changes state in the Inputs status area.
8. Click Save and restart.
9. After restart, verify the rate controller responds to master and rate commands.

## Example Setups

### Master And Rate Only, No Section Switches

Use this when only master and rate controls are installed.

Recommended settings:

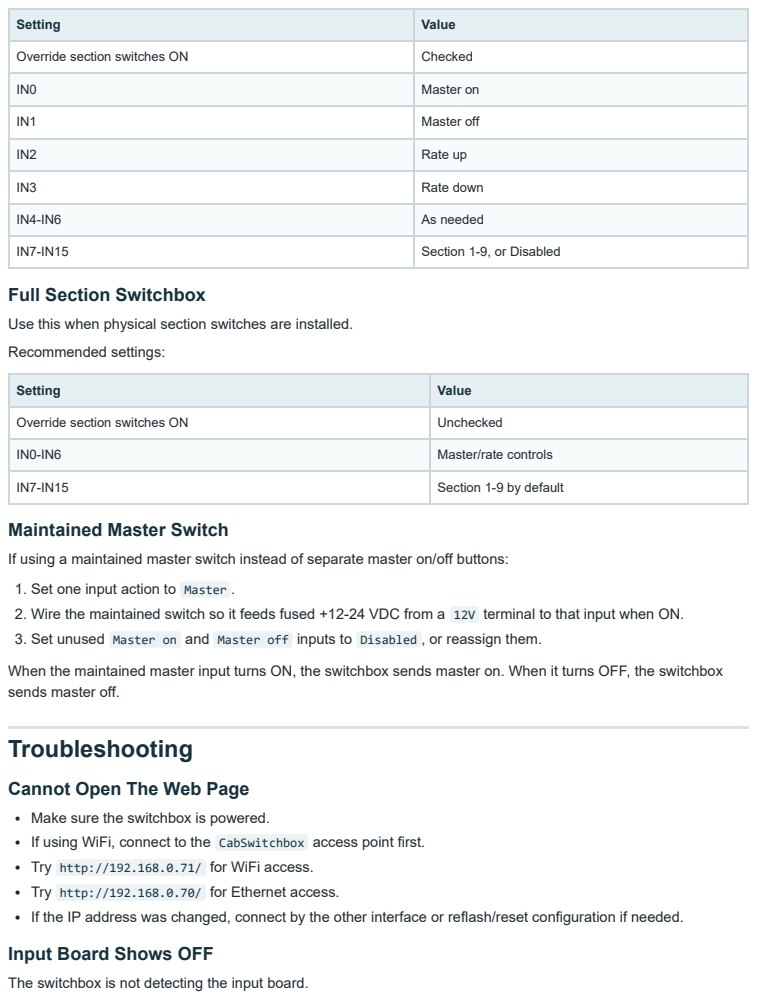
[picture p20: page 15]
Troubleshooting

Setting | Value

Override section switches ON | Checked

IN0 | Master on

IN1 | Master off

IN2 | Rate up

IN3 | Rate down

IN4-IN6 | As needed

IN7-IN15 | Section 1-9, or Disabled

Full Section Switchbox

Use this when physical section switches are installed.
Recommended settings:

Override section switches ON | Unchecked

IN0-IN6 | Master/rate controls

IN7-IN15 | Section 1-9 by default

Maintained Master Switch

If using a maintained master switch instead of separate master on/off buttons:
1. Set one input action to Master .
2. Wire the maintained switch so it feeds fused +12-24 VDC from a 12V terminal to that input when ON.
3. Set unused Master on and Master off inputs to Disabled , or reassign them.

When the maintained master input turns ON, the switchbox sends master on. When it turns OFF, the switchbox
sends master off.

Cannot Open The Web Page

Make sure the switchbox is powered.
If using WiFi, connect to the CabSwitchbox access point first.
Try http://192.168.0.71/ for WiFi access.
Try http://192.168.0.70/ for Ethernet access.
If the IP address was changed, connect by the other interface or reflash/reset configuration if needed.
Input Board Shows OFF

The switchbox is not detecting the input board.

Check:

Input board power and ground I2C SDA/SCL wiring
Soldering around the input board

If Input board is OFF, switch input states will not be reliable.

### Ethernet Shows OFF

Check:

Ethernet cable
Link lights on the W5500 module or connector Network switch/router
W5500 SPI wiring and chip select

The switchbox can still be configured by WiFi if Ethernet is unavailable.

### Inputs Do Not Turn ON

For the switchbox5 board, each input needs +12-24 VDC on the INx terminal to turn ON.

Check:

The switch feed has +12-24 VDC.
The switch output is connected to the correct INx terminal.
The 12-24 VDC supply negative is connected to switchbox input GND . The input is assigned to the expected action in the setup page.

### Missing Section Switches Stop Operation

Enable Override section switches ON. This forces section switch bits ON without changing master or rate input behavior.

### Rate Up Or Rate Down Sticks ON

Check whether the input is assigned to Rate up or Rate down and whether the physical switch is stuck active. The status page shows live input states.

Check whether the physical switch is stuck on, or whether +12-24 VDC is being backfed into that input.

### WiFi Station Does Not Connect

Check:

SSID spelling
Password spelling
WiFi signal strength
Whether the WiFi network uses a compatible 2.4 GHz mode

The switchbox access point remains available even when station WiFi is enabled.

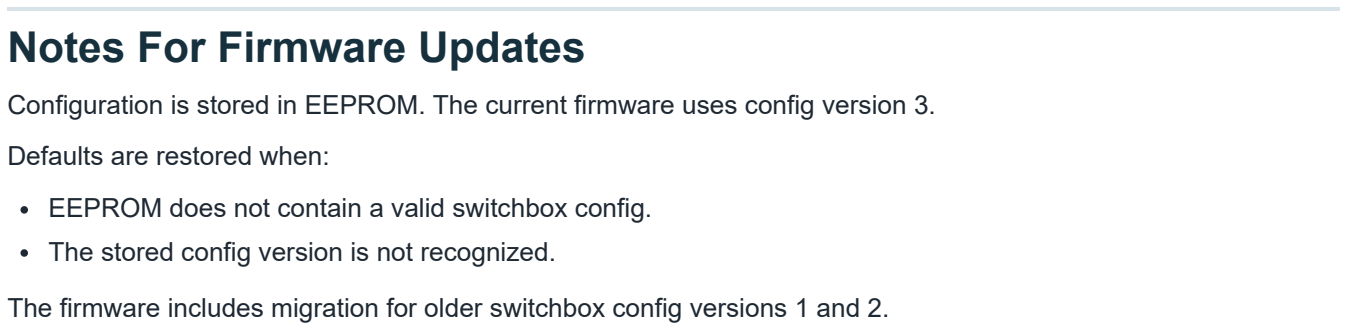
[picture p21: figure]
Notes For Firmware Updates; Defaults are restored when:

Configuration is stored in EEPROM. The current firmware uses config version 3.

EEPROM does not contain a valid switchbox config.
The stored config version is not recognized.

The firmware includes migration for older switchbox config versions 1 and 2.

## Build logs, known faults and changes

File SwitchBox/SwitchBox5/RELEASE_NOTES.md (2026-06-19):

# Release Notes

## Cab Switchbox 5 — June 19, 2026

- Supports 16 configurable 12-24 VDC switch inputs.
- Ethernet and WiFi communication with the Rate Controller.
- Web-based setup, status, and troubleshooting pages.
- Board-mounted 12 V alarm buzzer with Off, Reduced, and Full settings.
- Rate Controller alarm packet support.
- Rev 01 terminal PCB documentation and production files.
- Updated manual for the Hammond E1555K2GY NEMA 4X enclosure.

### Important power note

The PCB inputs and electronics support 12-24 VDC. The installed buzzer is a
12 V component connected to input power, so buzzer operation requires a 12 V
board supply.

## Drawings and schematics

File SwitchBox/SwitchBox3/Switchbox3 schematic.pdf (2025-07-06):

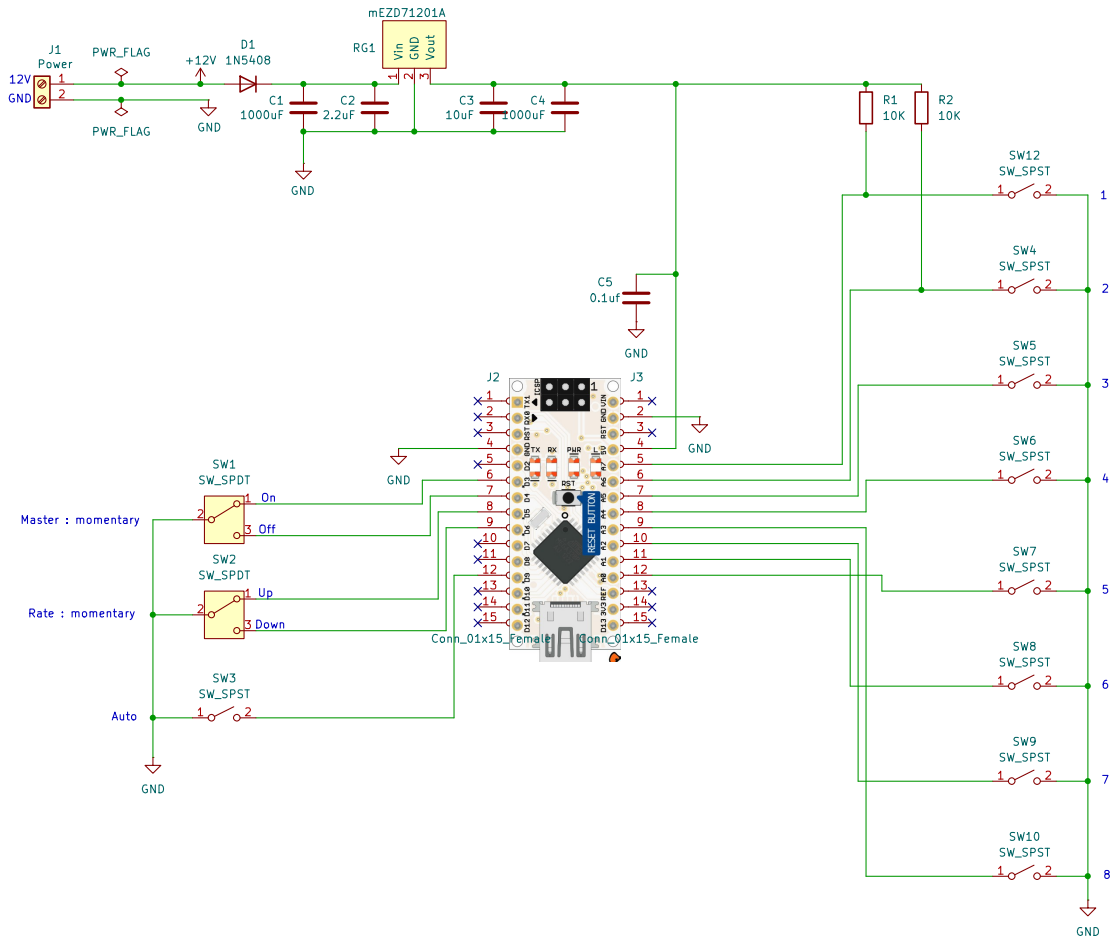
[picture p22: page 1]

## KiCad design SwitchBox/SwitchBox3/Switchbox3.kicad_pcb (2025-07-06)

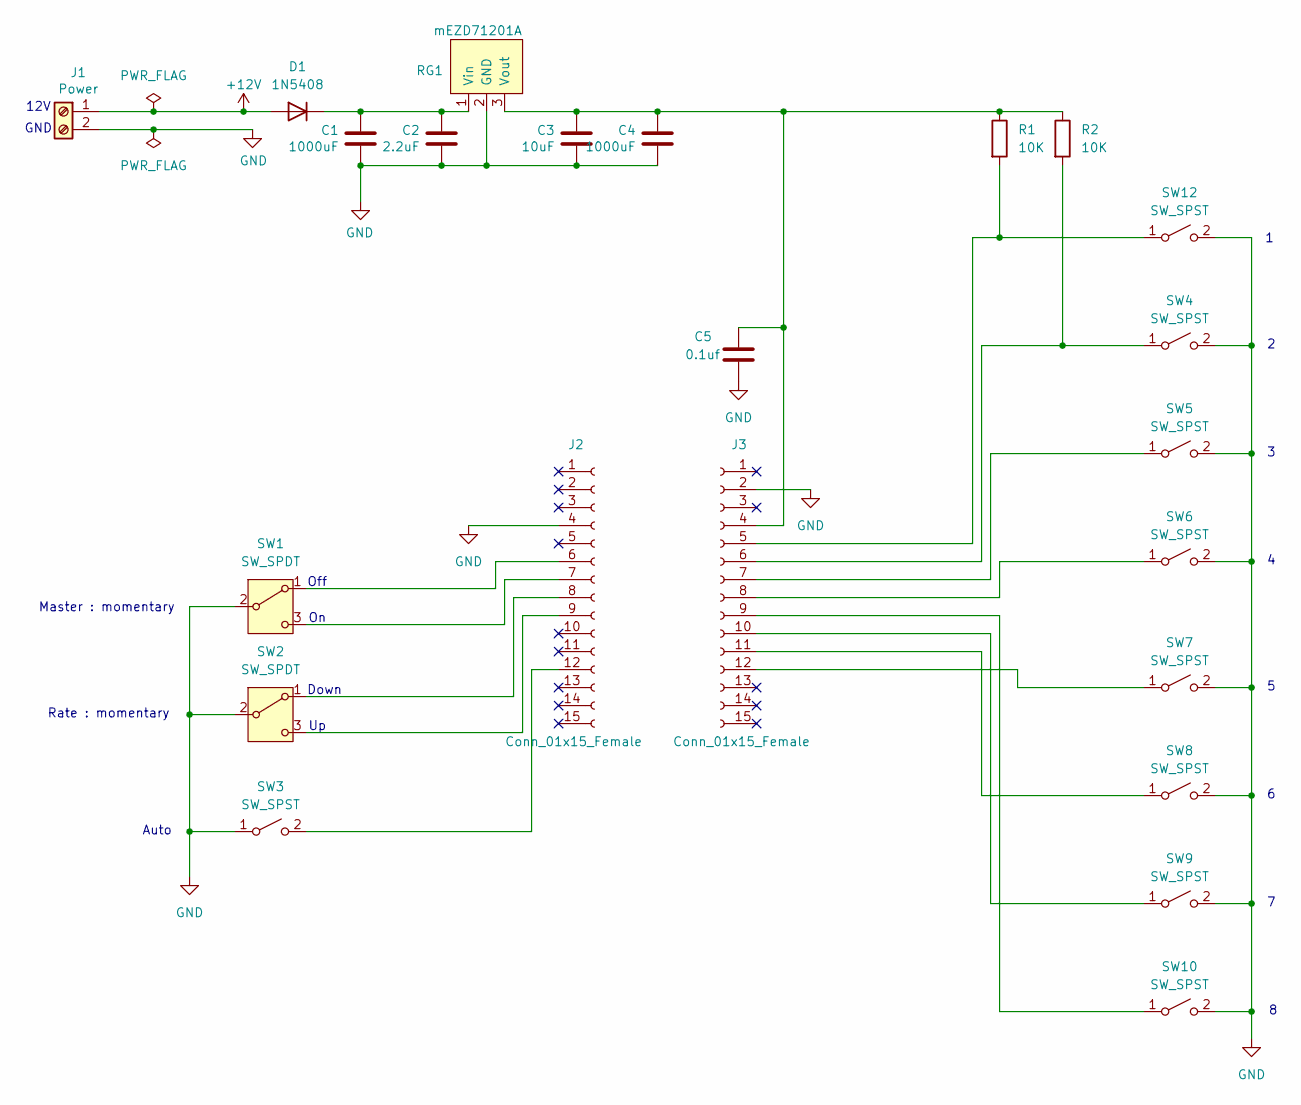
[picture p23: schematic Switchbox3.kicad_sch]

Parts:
C1, C4: 1000uF; CP_Radial_D10.0mm_P5.00mm
C2: 2.2uF; C_Disc_D5.0mm_W2.5mm_P2.50mm
C3: 10uF; C_Disc_D5.0mm_W2.5mm_P2.50mm
C5: 0.1uf; C_Disc_D5.0mm_W2.5mm_P2.50mm
D1: 1N5408
J1: Power; TerminalBlock_Phoenix_PT-1,5-2-5.0-H_1x02_P5.00mm_Horizontal
J2, J3: Conn_01x15_Female; PinSocket_1x15_P2.54mm_Vertical
R1, R2: 10K; R_Axial_DIN0207_L6.3mm_D2.5mm_P10.16mm_Horizontal
RG1: mEZD71201A
SW1, SW2: SW_SPDT; Mini_Toggle_3pin
SW3, SW4, SW5, SW6, SW7, SW8, SW9, SW10, SW12: SW_SPST; Mini_Toggle_2pin

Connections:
+12V: D1.2 (A), J1.1
GND: C1.2, C2.2, C3.2, C4.2, C5.1, J1.2, J2.4, J3.2, RG1.2 (GND), SW1.2 (B), SW2.2 (B), SW3.1 (A), SW4.2 (B), SW5.2 (B), SW6.2 (B), SW7.2 (B), SW8.2 (B), SW9.2 (B), SW10.2 (B), SW12.2 (B)
unnamed: C1.1, C2.1, D1.1 (K), RG1.1 (Vin)
unnamed: J2.6, SW1.1 (A)
unnamed: J2.7, SW1.3 (C)
unnamed: J2.8, SW2.1 (A)
unnamed: J2.9, SW2.3 (C)
unnamed: J2.12, SW3.2 (B)
unnamed: C3.1, C4.1, C5.2, J3.4, R1.1, R2.1, RG1.3 (Vout)
unnamed: J3.5, R1.2, SW12.1 (A)
unnamed: J3.6, R2.2, SW4.1 (A)
unnamed: J3.7, SW5.1 (A)
unnamed: J3.8, SW6.1 (A)
unnamed: J3.9, SW10.1 (A)
unnamed: J3.10, SW9.1 (A)
unnamed: J3.11, SW8.1 (A)
unnamed: J3.12, SW7.1 (A)

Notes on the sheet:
Off
Rate : momentary
Down
Master : momentary
12V
Auto
GND

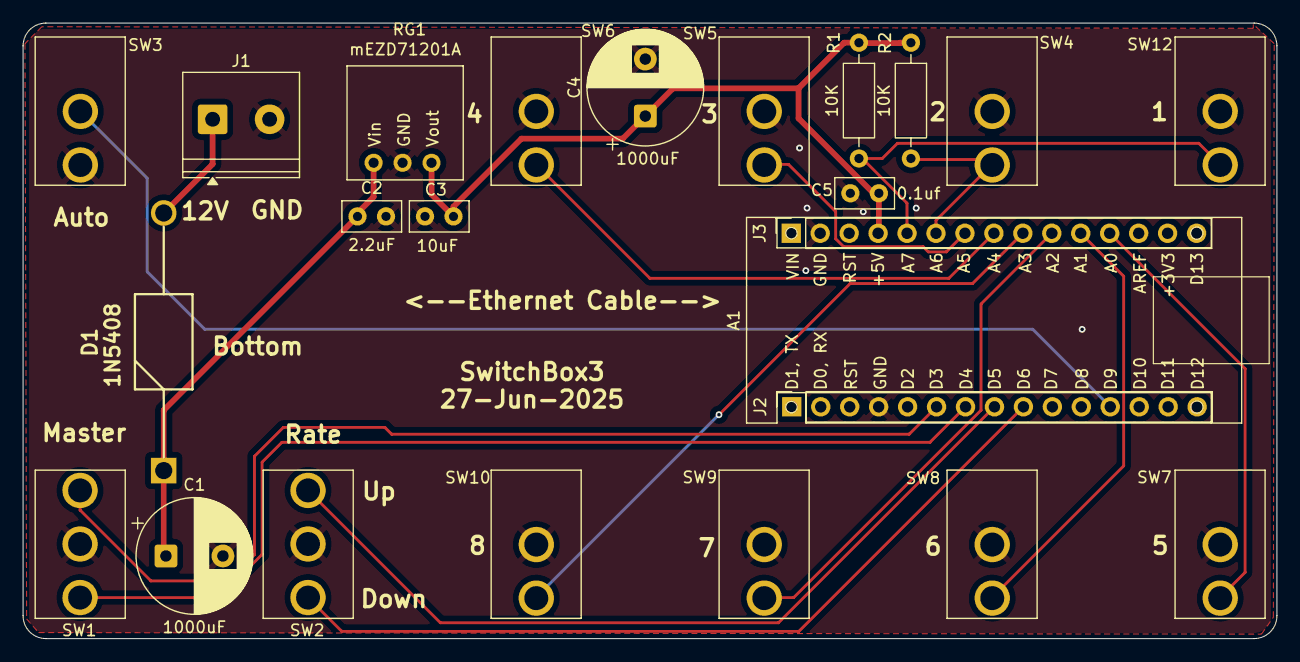
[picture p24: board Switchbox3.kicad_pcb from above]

Board: 2 copper layers, 110.0 x 54.0 mm, 24 parts (0 on the bottom side), 17 nets.

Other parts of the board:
A1: Arduino_Nano_v3.x; Arduino_Nano_outline

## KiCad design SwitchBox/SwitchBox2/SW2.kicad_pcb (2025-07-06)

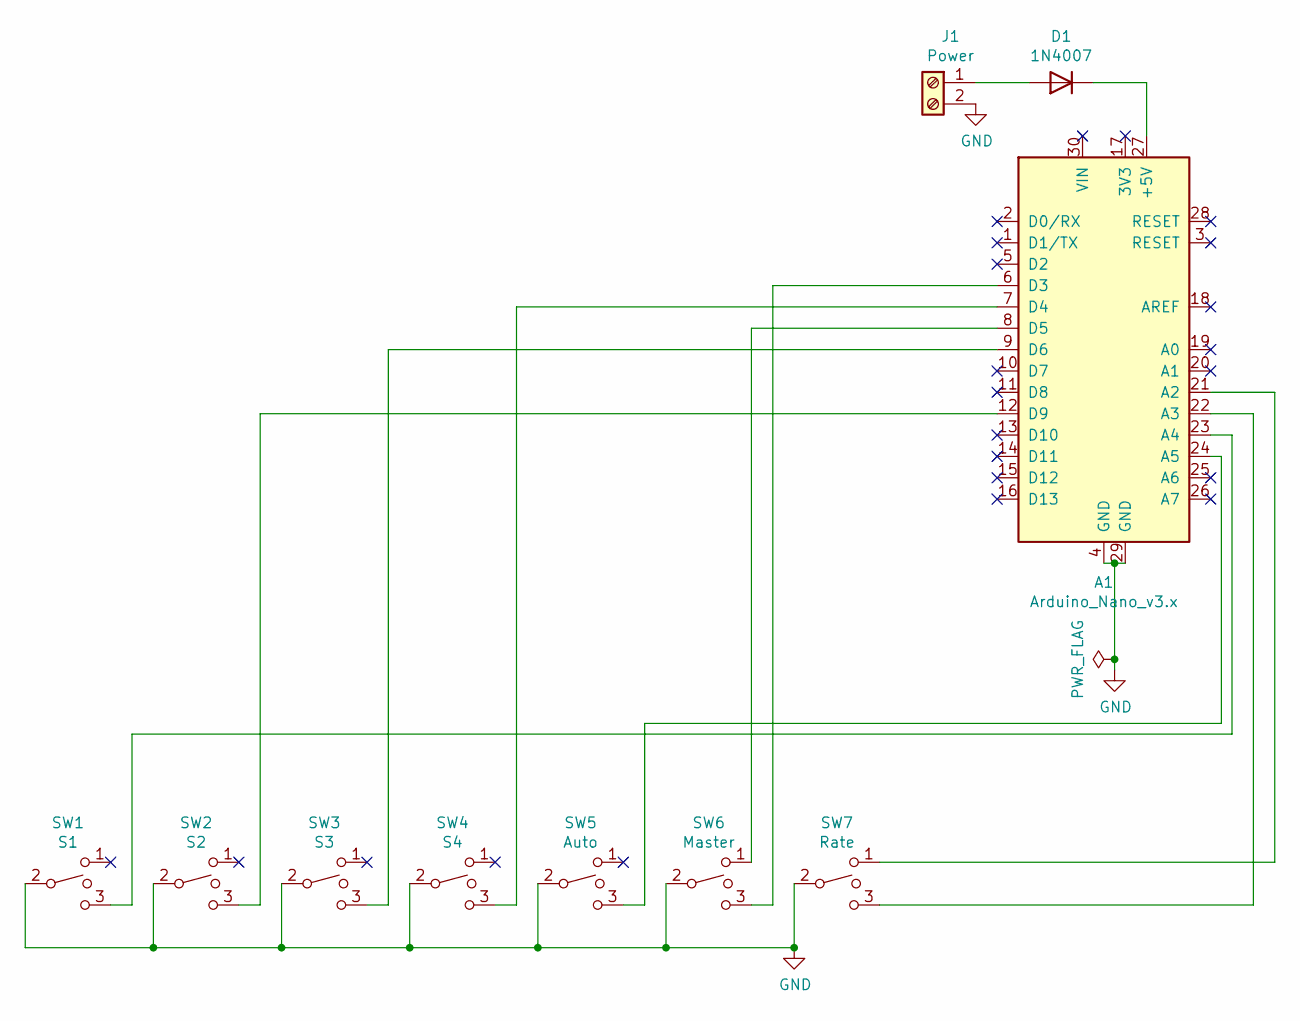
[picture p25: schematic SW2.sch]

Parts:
A1: Arduino_Nano_v3.x; Arduino_Nano
D1: 1N4007; D_DO-41_SOD81_P10.16mm_Horizontal
J1: Power; TerminalBlock_Phoenix_PT-1,5-2-5.0-H_1x02_P5.00mm_Horizontal
SW1: S1; Mini_Toggle_3pin
SW2: S2; Mini_Toggle_3pin
SW3: S3; Mini_Toggle_3pin
SW4: S4; Mini_Toggle_3pin
SW5: Auto; Mini_Toggle_3pin
SW6: Master; Mini_Toggle_3pin
SW7: Rate; Mini_Toggle_3pin

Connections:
GND: A1.4 (GND), A1.29 (GND), J1.2, SW1.2, SW2.2, SW3.2, SW4.2, SW5.2, SW6.2, SW7.2
unnamed: A1.6 (D3), SW6.3
unnamed: A1.7 (D4), SW4.3
unnamed: A1.8 (D5), SW6.1
unnamed: A1.9 (D6), SW3.3
unnamed: A1.12 (D9), SW2.3
unnamed: A1.21 (A2), SW7.1
unnamed: A1.22 (A3), SW7.3
unnamed: A1.23 (A4), SW1.3
unnamed: A1.24 (A5), SW5.3
unnamed: A1.27 (+5V), D1.1 (K)
unnamed: D1.2 (A), J1.1

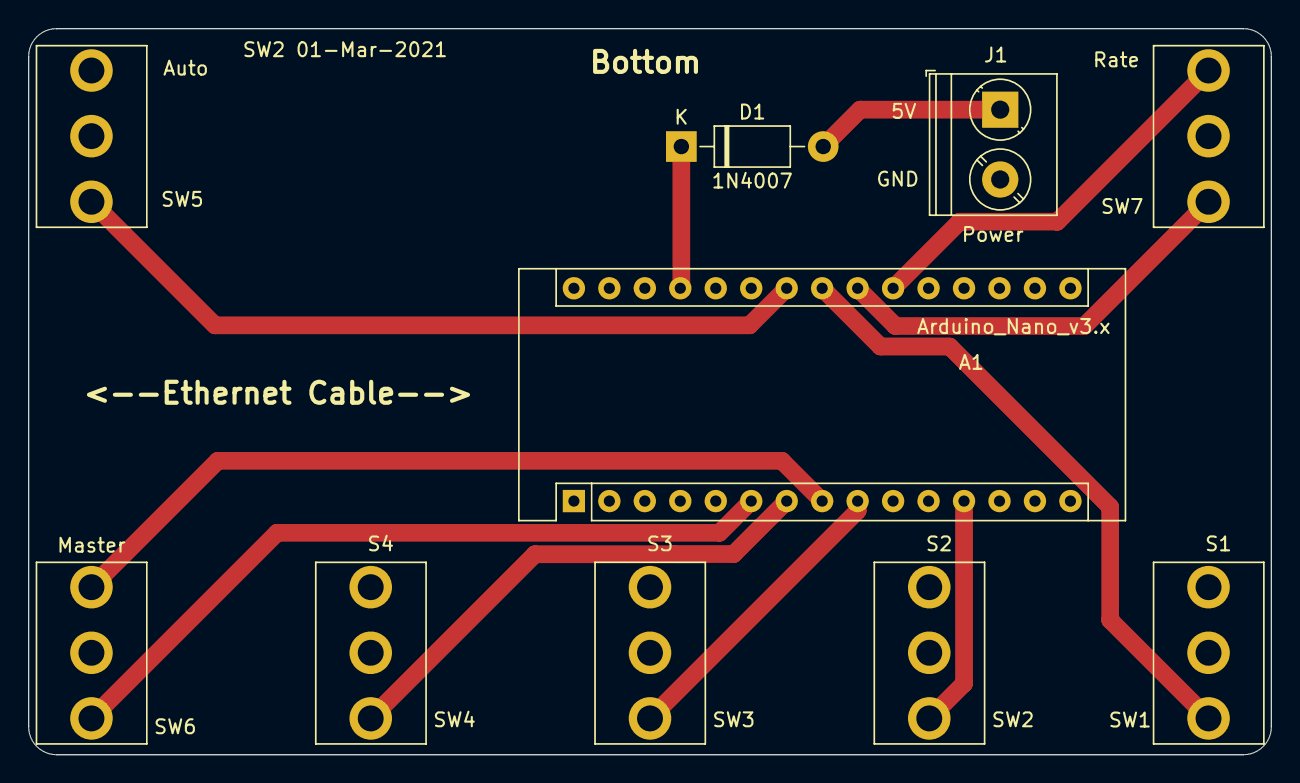
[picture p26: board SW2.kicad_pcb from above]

Board: 2 copper layers, 89.0 x 52.0 mm, 10 parts (0 on the bottom side), 12 nets.

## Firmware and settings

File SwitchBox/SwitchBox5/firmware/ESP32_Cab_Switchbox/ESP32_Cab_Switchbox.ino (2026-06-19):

#include <WiFi.h>
#include <WebServer.h>
#include <WiFiUdp.h>
#include <WiFiClient.h>
#include <DNSServer.h>
#include <ESPmDNS.h>
#include <EEPROM.h>
#include <Wire.h>
#include <SPI.h>
#include <Ethernet_Generic.h>
#include <EthernetUdp.h>

#define INO_DESCRIPTION "ESP32_Cab_Switchbox"

const uint16_t INO_ID = 24056;
const uint16_t EEPROM_SIZE = 512;
const uint32_t CONFIG_MAGIC = 0x53574258UL; // SWBX
const uint8_t CONFIG_VERSION = 3;
const uint8_t LEGACY_CONFIG_VERSION = 1;
const uint8_t SECTION_SWITCH_REQUIRED_CONFIG_VERSION = 2;

const uint8_t MCP23017_ADDRESS = 0x20;
const uint8_t W5500_CS_PIN = 5;
const uint8_t BUZZER_PIN = 27;
const uint16_t RATE_CONTROLLER_PORT = 29999;
const uint16_t LOCAL_UDP_PORT = 28888;
const uint16_t WEB_PORT = 80;
const uint16_t AP_DNS_PORT = 53;
const char* MDNS_NAME = "cabswitchbox";
const uint16_t BUZZER_TEST_MS = 2000;
const uint16_t ALARM_PACKET_TIMEOUT_MS = 3000;
const uint16_t BUZZER_VOLUME_FRAME_MS = 25;
const uint16_t BUZZER_REDUCED_ON_MS = 14;

enum InputAction : uint8_t
{
  ACT_DISABLED = 0,
  ACT_AUTO_MODE = 1,
  ACT_MANUAL_MODE = 2,
  ACT_OFF_MODE = 3,
  ACT_MASTER_ON = 4,
  ACT_MASTER_OFF = 5,
  ACT_RATE_UP = 6,
  ACT_RATE_DOWN = 7,
  ACT_WORK_SWITCH = 8,
  ACT_AUTO_SECTION = 9,
  ACT_AUTO_RATE = 10,
  ACT_RATE_2 = 11,
  ACT_MASTER_SWITCH = 12,
  ACT_SECTION_1 = 20,
  ACT_SECTION_2 = 21,
  ACT_SECTION_3 = 22,
  ACT_SECTION_4 = 23,
  ACT_SECTION_5 = 24,
  ACT_SECTION_6 = 25,
  ACT_SECTION_7 = 26,
  ACT_SECTION_8 = 27,
  ACT_SECTION_9 = 28,
  ACT_SECTION_10 = 29,
  ACT_SECTION_11 = 30,
  ACT_SECTION_12 = 31,
  ACT_SECTION_13 = 32,
  ACT_SECTION_14 = 33,
  ACT_SECTION_15 = 34,
  ACT_SECTION_16 = 35
};

enum CabMode : uint8_t
{
  MODE_OFF = 0,
  MODE_MANUAL = 1,
  MODE_AUTO = 2
};

struct SwitchboxConfig
{
  uint32_t magic;
  uint8_t version;
  uint8_t ethIp[4];
  uint8_t wifiIp[4];
  uint8_t gateway[4];
  uint8_t subnet[4];
  bool wifiStationEnabled;
  char ssid[32];
  char password[32];
  char apName[32];
  char apPassword[32];
  bool inputActiveLow;
  uint16_t sendPeriodMs;
  uint16_t pulseMs;
  uint8_t inputAction[16];
  bool overrideSectionSwitchesOn;
  uint8_t buzzerVolume;
};

SwitchboxConfig Cfg;

EthernetUDP UdpEth;
EthernetServer EthServer(WEB_PORT);
WiFiUDP UdpWifi;
WebServer WifiServer(WEB_PORT);
DNSServer DnsServer;

bool EthernetHardwareFound = false;
bool McpFound = false;
bool LastInputActive[16] = { false };
bool InputActive[16] = { false };
uint16_t RawMcpInputs = 0;
CabMode Mode = MODE_OFF;
uint32_t LastSendMs = 0;
uint32_t MasterOnPulseUntil = 0;
uint32_t MasterOffPulseUntil = 0;
uint32_t RateUpPulseUntil = 0;
uint32_t RateDownPulseUntil = 0;
uint32_t BuzzerTestUntil = 0;
uint32_t LastAlarmPacketMs = 0;
uint8_t AlarmStatus = 0;
uint8_t AlarmPattern = 0;
bool BuzzerOutputOn = false;

uint8_t NormalizeBuzzerLevel(uint8_t raw)
{
  if (raw <= 2) return raw;
  if (raw == 0) return 0;
  if (raw < 67) return 1;
  return 2;
}

const char* BuzzerLevelName(uint8_t level)
{
  switch (NormalizeBuzzerLevel(level))
  {
  case 0: return "Off";
  case 1: return "Reduced";
  default: return "Full";
  }
}

String DefaultApName()
{
  uint64_t mac = ESP.getEfuseMac();
  uint16_t suffix = (uint16_t)(mac & 0xFFFF);
  char name[32];
  snprintf(name, sizeof(name), "CabSwitchbox-%04X", suffix);
  return String(name);
}

void ApplyDefaultApNameIfNeeded()
{
  String current = String(Cfg.apName);
  if (current.length() == 0 || current == "CabSwitchbox")
  {
    String apName = DefaultApName();
    apName.toCharArray(Cfg.apName, sizeof(Cfg.apName));
  }
}

const char* ActionName(uint8_t action)
{
  switch (action)
  {
  case ACT_DISABLED: return "Disabled";
  case ACT_AUTO_MODE: return "Auto mode";
  case ACT_MANUAL_MODE: return "Manual mode";
  case ACT_OFF_MODE: return "Off mode";
  case ACT_MASTER_ON: return "Master on";
  case ACT_MASTER_OFF: return "Master off";
  case ACT_RATE_UP: return "Rate up";
  case ACT_RATE_DOWN: return "Rate down";
  case ACT_WORK_SWITCH: return "Work switch";
  case ACT_AUTO_SECTION: return "Manual section override";
  case ACT_AUTO_RATE: return "Manual rate override";
  case ACT_RATE_2: return "Rate 2";
  case ACT_MASTER_SWITCH: return "Master";
  case ACT_SECTION_1: return "Section 1";
  case ACT_SECTION_2: return "Section 2";
  case ACT_SECTION_3: return "Section 3";
  case ACT_SECTION_4: return "Section 4";
  case ACT_SECTION_5: return "Section 5";
  case ACT_SECTION_6: return "Section 6";
  case ACT_SECTION_7: return "Section 7";
  case ACT_SECTION_8: return "Section 8";
  case ACT_SECTION_9: return "Section 9";
  case ACT_SECTION_10: return "Section 10";
  case ACT_SECTION_11: return "Section 11";
  case ACT_SECTION_12: return "Section 12";
  case ACT_SECTION_13: return "Section 13";
  case ACT_SECTION_14: return "Section 14";
  case ACT_SECTION_15: return "Section 15";
  case ACT_SECTION_16: return "Section 16";
  default: return "Unknown";
  }
}

void SetDefaultConfig()
{
  memset(&Cfg, 0, sizeof(Cfg));
  Cfg.magic = CONFIG_MAGIC;
  Cfg.version = CONFIG_VERSION;
  Cfg.ethIp[0] = 192; Cfg.ethIp[1] = 168; Cfg.ethIp[2] = 0; Cfg.ethIp[3] = 70;
  Cfg.wifiIp[0] = 192; Cfg.wifiIp[1] = 168; Cfg.wifiIp[2] = 0; Cfg.wifiIp[3] = 71;
  Cfg.gateway[0] = 192; Cfg.gateway[1] = 168; Cfg.gateway[2] = 0; Cfg.gateway[3] = 1;
  Cfg.subnet[0] = 255; Cfg.subnet[1] = 255; Cfg.subnet[2] = 255; Cfg.subnet[3] = 0;
  Cfg.wifiStationEnabled = false;
  String apName = DefaultApName();
  apName.toCharArray(Cfg.apName, sizeof(Cfg.apName));
  strncpy(Cfg.apPassword, "", sizeof(Cfg.apPassword) - 1);
  Cfg.inputActiveLow = true;
  Cfg.overrideSectionSwitchesOn = false;
  Cfg.sendPeriodMs = 100;
  Cfg.pulseMs = 250;
  Cfg.buzzerVolume = 60;

  Cfg.inputAction[0] = ACT_MASTER_ON;     // IN0
  Cfg.inputAction[1] = ACT_MASTER_OFF;    // IN1
  Cfg.inputAction[2] = ACT_RATE_UP;       // IN2
  Cfg.inputAction[3] = ACT_RATE_DOWN;     // IN3
  Cfg.inputAction[4] = ACT_AUTO_RATE;     // IN4, asserted = manual rate override
  Cfg.inputAction[5] = ACT_AUTO_SECTION;  // IN5, asserted = manual section override
  Cfg.inputAction[6] = ACT_RATE_2;        // IN6
  Cfg.inputAction[7] = ACT_SECTION_1;     // IN7
  Cfg.inputAction[8] = ACT_SECTION_2;     // IN8
  Cfg.inputAction[9] = ACT_SECTION_3;     // IN9
  Cfg.inputAction[10] = ACT_SECTION_4;    // IN10
  Cfg.inputAction[11] = ACT_SECTION_5;    // IN11
  Cfg.inputAction[12] = ACT_SECTION_6;    // IN12
  Cfg.inputAction[13] = ACT_SECTION_7;    // IN13
  Cfg.inputAction[14] = ACT_SECTION_8;    // IN14
  Cfg.inputAction[15] = ACT_SECTION_9;    // IN15
}

IPAddress ToIp(const uint8_t parts[4])
{
  return IPAddress(parts[0], parts[1], parts[2], parts[3]);
}

IPAddress BroadcastFor(const uint8_t parts[4])
{
  return IPAddress(parts[0], parts[1], parts[2], 255);
}

uint8_t Crc(byte data[], byte length)
{
  uint8_t result = 0;
  for (byte i = 0; i < length; i++) result += data[i];
  return result;
}

void LoadConfig()
{
  EEPROM.get(0, Cfg);
  if (Cfg.magic == CONFIG_MAGIC && Cfg.version == LEGACY_CONFIG_VERSION)
  {
    Cfg.version = CONFIG_VERSION;
    Cfg.overrideSectionSwitchesOn = false;
    EEPROM.put(0, Cfg);
    EEPROM.commit();
  }
  else if (Cfg.magic == CONFIG_MAGIC && Cfg.version == SECTION_SWITCH_REQUIRED_CONFIG_VERSION)
  {
    Cfg.overrideSectionSwitchesOn = !Cfg.overrideSectionSwitchesOn;
    Cfg.version = CONFIG_VERSION;
    EEPROM.put(0, Cfg);
    EEPROM.commit();
  }
  else if (Cfg.magic != CONFIG_MAGIC || Cfg.version != CONFIG_VERSION)
  {
    SetDefaultConfig();
    EEPROM.put(0, Cfg);
    EEPROM.commit();
  }

  if (Cfg.sendPeriodMs < 50 || Cfg.sendPeriodMs > 1000) Cfg.sendPeriodMs = 100;
  if (Cfg.pulseMs < 50 || Cfg.pulseMs > 1000) Cfg.pulseMs = 250;
  Cfg.buzzerVolume = NormalizeBuzzerLevel(Cfg.buzzerVolume);
  Cfg.inputActiveLow = true;
  ApplyDefaultApNameIfNeeded();
}

void SaveConfig()
{
  Cfg.magic = CONFIG_MAGIC;
  Cfg.version = CONFIG_VERSION;
  EEPROM.put(0, Cfg);
  EEPROM.commit();
}

void SetupBuzzer()
{
  pinMode(BUZZER_PIN, OUTPUT);
  digitalWrite(BUZZER_PIN, LOW);
}

bool AlarmPacketIsLive()
{
  return LastAlarmPacketMs > 0 && (millis() - LastAlarmPacketMs) < ALARM_PACKET_TIMEOUT_MS;
}

bool AlarmIsActive()
{
  return AlarmPacketIsLive() && (AlarmStatus & 0x01);
}

bool AlarmPatternAllowsBeep()
{
  if (!AlarmIsActive()) return false;

  uint32_t phase = millis() % 1000;
  if (AlarmPattern == 2 || (AlarmStatus & 0x02)) return phase < 150 || (phase >= 300 && phase < 450);
  return phase < 350;
}

void DriveBuzzer(bool requestOn)
{
  uint8_t level = NormalizeBuzzerLevel(Cfg.buzzerVolume);
  bool outputOn = false;

  if (requestOn && level > 0)
  {
    if (level >= 2)
    {
      outputOn = true;
    }
    else
    {
      outputOn = (millis() % BUZZER_VOLUME_FRAME_MS) < BUZZER_REDUCED_ON_MS;
    }
  }

  if (outputOn != BuzzerOutputOn)
  {
    BuzzerOutputOn = outputOn;
    digitalWrite(BUZZER_PIN, outputOn ? HIGH : LOW);
  }
}

void UpdateBuzzer()
{
  bool testOn = millis() < BuzzerTestUntil;
  DriveBuzzer(testOn || AlarmPatternAllowsBeep());
}

void StartBuzzerTest()
{
  BuzzerTestUntil = millis() + BUZZER_TEST_MS;
}

void ParseAlarmPacket(byte data[], uint16_t len)
{
  if (len < 5) return;
  if (data[0] != 107 || data[1] != 127) return;
  if (data[4] != Crc(data, 4)) return;

  AlarmStatus = data[2];
  AlarmPattern = data[3];
  LastAlarmPacketMs = millis();
}

void ReceiveAlarmPackets()
{
  byte data[16];

  if (EthernetHardwareFound && Ethernet.linkStatus() == LinkON)
  {
    uint16_t len = UdpEth.parsePacket();
    if (len > 0)
    {
      if (len > sizeof(data)) len = sizeof(data);
      UdpEth.read(data, len);
      ParseAlarmPacket(data, len);
    }
  }

  uint16_t len = UdpWifi.parsePacket();
  if (len > 0)
  {
    if (len > sizeof(data)) len = sizeof(data);
    UdpWifi.read(data, len);
    ParseAlarmPacket(data, len);
  }
}

void SetupMcp23017()
{
  Wire.begin();

  Wire.beginTransmission(MCP23017_ADDRESS);
  McpFound = (Wire.endTransmission() == 0);
  if (!McpFound)
  {
    Serial.println("MCP23017 not found at 0x20.");
    return;
  }

  Wire.beginTransmission(MCP23017_ADDRESS);
  Wire.write(0x00); // IODIRA
  Wire.write(0xFF);
  Wire.write(0xFF); // IODIRB
  Wire.endTransmission();

  Wire.beginTransmission(MCP23017_ADDRESS);
  Wire.write(0x0C); // GPPUA
  Wire.write(0xFF);
  Wire.write(0xFF); // GPPUB
  Wire.endTransmission();

  Serial.println("MCP23017 found at 0x20.");
}

uint16_t ReadMcpInputs()
{
  if (!McpFound) return 0;

  Wire.beginTransmission(MCP23017_ADDRESS);
  Wire.write(0x12); // GPIOA
  if (Wire.endTransmission(false) != 0) return 0;

  if (Wire.requestFrom(MCP23017_ADDRESS, (uint8_t)2) != 2) return 0;
  uint8_t gpioA = Wire.read();
  uint8_t gpioB = Wire.read();
  return (uint16_t)gpioA | ((uint16_t)gpioB << 8);
}

void SetupEthernet()
{
  uint8_t mac[] = { 0xA8, 0x61, 0x0A, 0x70, 0x00, 0x01 };
  Ethernet.init(W5500_CS_PIN);
  Ethernet.begin(mac, ToIp(Cfg.ethIp), ToIp(Cfg.gateway), ToIp(Cfg.gateway), ToIp(Cfg.subnet));
  EthernetHardwareFound = (Ethernet.hardwareStatus() != EthernetNoHardware);

  if (!EthernetHardwareFound)
  {
    Serial.println("W5500 not found; Ethernet disabled.");
    return;
  }

  UdpEth.begin(LOCAL_UDP_PORT);
  EthServer.begin();
  Serial.print("Ethernet IP: ");
  Serial.println(Ethernet.localIP());
}

void SetupWifi()
{
  WiFi.mode(WIFI_AP_STA);
  WiFi.disconnect(true);
  delay(100);

  WiFi.softAPConfig(ToIp(Cfg.wifiIp), ToIp(Cfg.wifiIp), ToIp(Cfg.subnet));
  if (strlen(Cfg.apPassword) >= 8) WiFi.softAP(Cfg.apName, Cfg.apPassword);
  else WiFi.softAP(Cfg.apName);
  DnsServer.start(AP_DNS_PORT, "*", ToIp(Cfg.wifiIp));

  if (Cfg.wifiStationEnabled && strlen(Cfg.ssid) > 0)
  {
    WiFi.config(ToIp(Cfg.wifiIp), ToIp(Cfg.gateway), ToIp(Cfg.subnet));
    WiFi.begin(Cfg.ssid, Cfg.password);
  }

  UdpWifi.begin(LOCAL_UDP_PORT);
  WifiServer.on("/", HandleWifiRoot);
  WifiServer.on("/manual", HandleWifiManual);
  WifiServer.on("/save", HTTP_GET, HandleWifiSave);
  WifiServer.on("/status", HandleWifiStatus);
  WifiServer.on("/buzzer-test", HandleWifiBuzzerTest);
  WifiServer.begin();
  if (MDNS.begin(MDNS_NAME))
  {
    MDNS.addService("http", "tcp", WEB_PORT);
    Serial.print("mDNS: http://");
    Serial.print(MDNS_NAME);
    Serial.println(".local/");
  }

  Serial.print("WiFi setup IP: ");
  Serial.println(WiFi.softAPIP());
}

void PulseMasterOn()
{
  MasterOnPulseUntil = millis() + Cfg.pulseMs;
  MasterOffPulseUntil = 0;
}

void PulseMasterOff()
{
  MasterOffPulseUntil = millis() + Cfg.pulseMs;
  MasterOnPulseUntil = 0;
}

void SetMode(CabMode mode)
{
  if (Mode == mode) return;

  Mode = mode;
  if (Mode == MODE_OFF) PulseMasterOff();
  else PulseMasterOn();
}

void ApplyInputEdges()
{
  for (uint8_t i = 0; i < 16; i++)
  {
    if (Cfg.inputAction[i] == ACT_MASTER_SWITCH && InputActive[i] != LastInputActive[i])
    {
      if (InputActive[i]) PulseMasterOn();
      else PulseMasterOff();
      continue;
    }

    if (!InputActive[i] || LastInputActive[i]) continue;

    switch (Cfg.inputAction[i])
    {
    case ACT_AUTO_MODE:
      SetMode(MODE_AUTO);
      break;
    case ACT_MANUAL_MODE:
      SetMode(MODE_MANUAL);
      break;
    case ACT_OFF_MODE:
      SetMode(MODE_OFF);
      break;
    case ACT_MASTER_ON:
      PulseMasterOn();
      break;
    case ACT_MASTER_OFF:
      PulseMasterOff();
      break;
    case ACT_RATE_UP:
      RateUpPulseUntil = millis() + Cfg.pulseMs;
      RateDownPulseUntil = 0;
      break;
    case ACT_RATE_DOWN:
      RateDownPulseUntil = millis() + Cfg.pulseMs;
      RateUpPulseUntil = 0;
      break;
    }
  }

  memcpy(LastInputActive, InputActive, sizeof(InputActive));
}

bool AnyActionActive(uint8_t action)
{
  for (uint8_t i = 0; i < 16; i++)
  {
    if (Cfg.inputAction[i] == action && InputActive[i]) return true;
  }
  return false;
}

void ReadInputs()
{
  uint16_t raw = ReadMcpInputs();
  RawMcpInputs = raw;
  for (uint8_t i = 0; i < 16; i++)
  {
    bool high = ((raw & (1 << i)) != 0);
    InputActive[i] = !high;
  }
  ApplyInputEdges();
}

void BuildSwitchboxPacket(byte data[6])
{
  uint32_t now = millis();
  byte status = 0;
  byte sectionsLo = 0;
  byte sectionsHi = 0;

  if (now < MasterOnPulseUntil) status |= 0b00000010;
  if (now < MasterOffPulseUntil) status |= 0b00000100;
  if (now < RateUpPulseUntil || AnyActionActive(ACT_RATE_UP)) status |= 0b00001000;
  if (now < RateDownPulseUntil || AnyActionActive(ACT_RATE_DOWN)) status |= 0b00010000;

  if (AnyActionActive(ACT_RATE_2)) status |= 0b00000001;
  if (Mode == MODE_AUTO || !AnyActionActive(ACT_AUTO_SECTION)) status |= 0b00100000;
  if (Mode == MODE_AUTO || !AnyActionActive(ACT_AUTO_RATE)) status |= 0b01000000;
  if (AnyActionActive(ACT_WORK_SWITCH)) status |= 0b10000000;

  for (uint8_t i = 0; i < 16; i++)
  {
    uint8_t action = Cfg.inputAction[i];
    if (action >= ACT_SECTION_1 && action <= ACT_SECTION_16 && (Cfg.overrideSectionSwitchesOn || InputActive[i]))
    {
      uint8_t section = action - ACT_SECTION_1;
      if (section < 8) sectionsLo |= 1 << section;
      else sectionsHi |= 1 << (section - 8);
    }
  }

  data[0] = 106;
  data[1] = 127;
  data[2] = status;
  data[3] = sectionsLo;
  data[4] = sectionsHi;
  data[5] = Crc(data, 5);
}

void SendSwitchboxPacket()
{
  if (millis() - LastSendMs < Cfg.sendPeriodMs) return;
  LastSendMs = millis();

  byte data[6];
  BuildSwitchboxPacket(data);

  if (EthernetHardwareFound && Ethernet.linkStatus() == LinkON)
  {
    UdpEth.beginPacket(BroadcastFor(Cfg.ethIp), RATE_CONTROLLER_PORT);
    UdpEth.write(data, sizeof(data));
    UdpEth.endPacket();
  }

  UdpWifi.beginPacket(BroadcastFor(Cfg.wifiIp), RATE_CONTROLLER_PORT);
  UdpWifi.write(data, sizeof(data));
  UdpWifi.endPacket();
}

void SetupWeb()
{
}

String IpFields(const char* name, const uint8_t ip[4])
{
  String s;
  for (uint8_t i = 0; i < 4; i++)
  {
    s += "<input name='";
    s += name;
    s += i;
    s += "' type='number' min='0' max='255' value='";
    s += ip[i];
    s += "'>";
  }
  return s;
}

String ActionOptions(uint8_t selected)
{
  const uint8_t actions[] = {
    ACT_DISABLED, ACT_MASTER_ON, ACT_MASTER_OFF,
    ACT_RATE_UP, ACT_RATE_DOWN, ACT_WORK_SWITCH, ACT_AUTO_SECTION, ACT_AUTO_RATE, ACT_RATE_2,
    ACT_MASTER_SWITCH,
    ACT_SECTION_1, ACT_SECTION_2, ACT_SECTION_3, ACT_SECTION_4, ACT_SECTION_5, ACT_SECTION_6,
    ACT_SECTION_7, ACT_SECTION_8, ACT_SECTION_9, ACT_SECTION_10, ACT_SECTION_11, ACT_SECTION_12,
    ACT_SECTION_13, ACT_SECTION_14, ACT_SECTION_15, ACT_SECTION_16
  };

  String s;
  for (uint8_t i = 0; i < sizeof(actions); i++)
  {
    uint8_t action = actions[i];
    s += "<option value='";
    s += action;
    s += "'";
    if (action == selected) s += " selected";
    s += ">";
    s += ActionName(action);
    s += "</option>";
  }
  return s;
}

String StatusJson()
{
  byte data[6];
  BuildSwitchboxPacket(data);

  String s = "{";
  s += "\"mcp\":";
  s += McpFound ? "true" : "false";
  s += ",\"ethernet\":";
  s += (EthernetHardwareFound && Ethernet.linkStatus() == LinkON) ? "true" : "false";
  s += ",\"wifiStation\":";
  s += WiFi.isConnected() ? "true" : "false";
  s += ",\"wifiRssi\":";
  s += WiFi.isConnected() ? WiFi.RSSI() : 0;
  s += ",\"mode\":";
  s += Mode;
  s += ",\"rawMcp\":";
  s += RawMcpInputs;
  s += ",\"rawA\":";
  s += (RawMcpInputs & 0xFF);
  s += ",\"rawB\":";
  s += (RawMcpInputs >> 8);
  s += ",\"status\":";
  s += data[2];
  s += ",\"crc\":";
  s += data[5];
  s += ",\"masterOn\":";
  s += (data[2] & 0b00000010) ? "true" : "false";
  s += ",\"masterOff\":";
  s += (data[2] & 0b00000100) ? "true" : "false";
  s += ",\"rateUp\":";
  s += (data[2] & 0b00001000) ? "true" : "false";
  s += ",\"rateDown\":";
  s += (data[2] & 0b00010000) ? "true" : "false";
  s += ",\"autoSection\":";
  s += (data[2] & 0b00100000) ? "true" : "false";
  s += ",\"autoRate\":";
  s += (data[2] & 0b01000000) ? "true" : "false";
  s += ",\"rate2\":";
  s += (data[2] & 0b00000001) ? "true" : "false";
  s += ",\"work\":";
  s += (data[2] & 0b10000000) ? "true" : "false";
  s += ",\"sectionsLo\":";
  s += data[3];
  s += ",\"sectionsHi\":";
  s += data[4];
  s += ",\"overrideSectionSwitchesOn\":";
  s += Cfg.overrideSectionSwitchesOn ? "true" : "false";
  s += ",\"buzzerLevel\":";
  s += NormalizeBuzzerLevel(Cfg.buzzerVolume);
  s += ",\"buzzerLevelName\":\"";
  s += BuzzerLevelName(Cfg.buzzerVolume);
  s += "\"";
  s += ",\"buzzerOn\":";
  s += BuzzerOutputOn ? "true" : "false";
  s += ",\"buzzerTest\":";
  s += (millis() < BuzzerTestUntil) ? "true" : "false";
  s += ",\"alarmActive\":";
  s += AlarmIsActive() ? "true" : "false";
  s += ",\"alarmLive\":";
  s += AlarmPacketIsLive() ? "true" : "false";
  s += ",\"alarmStatus\":";
  s += AlarmStatus;
  s += ",\"alarmPattern\":";
  s += AlarmPattern;
  s += ",\"packet\":[";
  for (uint8_t i = 0; i < 6; i++)
  {
    if (i) s += ",";
    s += data[i];
  }
  s += "]";
  s += ",\"actions\":[";
  for (uint8_t i = 0; i < 16; i++)
  {
    if (i) s += ",";
    s += "\"";
    s += ActionName(Cfg.inputAction[i]);
    s += "\"";
  }
  s += "]";
  s += ",\"inputs\":[";
  for (uint8_t i = 0; i < 16; i++)
  {
    if (i) s += ",";
    s += InputActive[i] ? "true" : "false";
  }
  s += "]}";
  return s;
}
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
void loop()
{
  DnsServer.processNextRequest();
  WifiServer.handleClient();
  HandleEthernetWeb();
  ReadInputs();
  ReceiveAlarmPackets();
  SendSwitchboxPacket();
  UpdateBuzzer();
}

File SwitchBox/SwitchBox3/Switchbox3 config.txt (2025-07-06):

Switchbox3

Auto		9
Master On	4
Master Off	3
Rate Up		6
Rate Down	5
Work Switch	0

Switch 1	21
Switch 2	20
Switch 3	19
Switch 4	18
Switch 5	14
Switch 6	15
Switch 7	16
Switch 8	17

Switch 9	0
Switch 10	0
Switch 11	0
Switch 12	0
Switch 13	0
Switch 14	0
Switch 15	0
Switch 16	0

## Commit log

2025-07-06 add Switchbox3
    [SW2 Parts.xls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]
2026-06-19 Create SwitchBox5
2026-06-19 Create SwitchBox5_PCB_01
